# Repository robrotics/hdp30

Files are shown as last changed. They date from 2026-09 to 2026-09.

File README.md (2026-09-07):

# HDP30: a 3D-printable 30:1 pancake harmonic drive actuator

A strain-wave (harmonic) gearbox that bolts onto a standard NEMA 17 stepper,
prints on a bog-standard bed slinger, and costs about **$4 of hardware** per
unit. Half again the reduction of our [HD20](https://github.com/robrotics/hd17)
in a thinner package, using the same screws, the same bearing and the same
motor face.

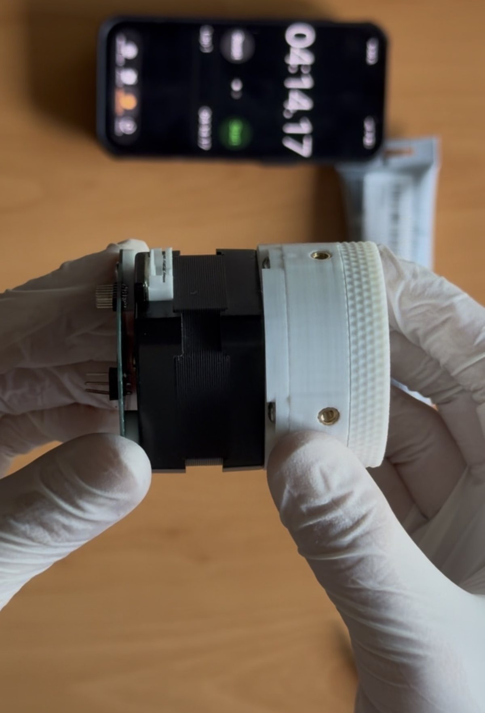
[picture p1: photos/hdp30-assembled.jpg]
The HDP30 assembled on a NEMA 17


| | |
|---|---|
| **Reduction** | 30:1 |
| **Tooth profile** | Cycloidal, module 0.55, 60-tooth flexspline / 62-tooth circular spline |
| **Measured torque** | **not yet measured**, see [Test data](#test-data) |
| **Efficiency** | not yet measured |
| **Backlash** | not yet measured |
| **Motor** | Any NEMA 17 with a 5 mm shaft (same interface plate as the HD20) |
| **Lubrication** | Super Lube synthetic PTFE grease |
| **Printed parts** | 10 pieces across 9 unique parts, including 2 shear pins |
| **Fasteners** | 8 × M3×0.5 × 6 mm button head screws per drive |
| **Hardware cost** | ~$3.96 per actuator |
| **Version** | v1.0 (RevB, 2026-08-30) |
| **License** | [CC BY-SA 4.0](LICENSE) |

> ⚠️ **This revision has not been tested on a load cell yet.** There is no
> torque number, no efficiency number and no backlash number for the HDP30,
> and we would rather ship the files with that gap stated plainly than quote
> you the HD20's figures and let you assume they carry over. They don't: the
> tooth module dropped from 0.8 to 0.55, so the teeth are smaller and the
> engagement is different. Testing is queued; this page gets the numbers when
> the numbers exist.
>
> If you build one and measure it before we do, please
> [open an issue](https://github.com/robrotics/hdp30/issues). We'll credit you.

---

## How it works

Three parts do the work. A **wave generator**, an ellipse riding on 11 loose
5 mm balls in a printed cage, pushes a flexible toothed ring (the
**flexspline**) into an oval, so its teeth engage a rigid ring (the **circular
spline**) at just two points. The circular spline has two more teeth than the
flexspline, so one turn of the motor walks the output around by two teeth.
With a 60-tooth flexspline, that tiny slip per revolution is the 30:1.

New to strain-wave gearing? We wrote a plain-language explainer:
**[robrotics.web.app/learn](https://robrotics.web.app/learn)**.

## What changed from the HD20

The HD20 got 20:1 out of a 40-tooth flexspline at module 0.8. The HDP30 keeps
the same two-tooth difference but packs in **60 teeth at module 0.55**, which
buys half again the reduction at roughly the same pitch diameter, and lets the
whole stack get thinner, hence *pancake*.

Six parts were re-cut for the new profile: the flexspline, both circular
splines, the wave generator, the ball cage and the output preloader. The
**interface plate, the base preloader and the shear pins are unchanged**, and
so is every piece of hardware: same 11 balls, same 30×42×7 bearing, same 8
screws, same 12 inserts. If you have already built an HD20, your leftovers
cover this one.

What you give up is the test data. The HD20 is the measured design; the HDP30
is the newer one.

## What you need

**Not included in the BOM, bring your own:**

- A **NEMA 17 stepper with a 5 mm shaft**. The interface plate is unchanged
  from the HD20, which was validated with an
  [OMC StepperOnline 17HE12-1204S](https://www.omc-stepperonline.com/e-series-nema-17-bipolar-26ncm-36-82oz-in-1-2a-42x42x30mm-4-wires-w-1m-cable-connector-17he12-1204s)
  (42 × 42 × 30 mm, 26 N·cm, 1.2 A, 4-wire) under closed-loop FOC control.
- **4 × M3 screws** to bolt the motor to the interface plate. These are
  separate from the 8 × M3×0.5 × 6 mm screws that hold the drive together,
  which are in the BOM.
- A **soldering iron** for the heat-set inserts, and hex keys.

**Filament:** PLA for everything except the flexspline, which must be **PETG**.

> ⚠️ **Do not print the flexspline in PLA.** It flexes on every single
> revolution. PLA has almost no fatigue life in that duty and will crack.
> This matters more here than on the HD20, not less. Module 0.55 teeth are
> smaller, and the wall they sit on is thin.

## Bill of materials

Machine-readable source: [`bom.json`](bom.json).

| # | Item | Qty | Pack | Pack cost | Per actuator |
|---|---|-----|---|---|---|
| 1 | M3 heat-set inserts | 12 | 100 | $9.99 | $1.20 |
| 2 | M3×0.5 × 6 mm button head, stainless | 8 | 100 | $7.69 | $0.62 |
| 3 | 30 × 42 × 7 mm bearing | 1 | 10 | $16.39 | $1.64 |
| 4 | Set screw | 1 | 50 | $5.69 | $0.11 |
| 5 | 5 mm steel bearing balls | 11 | 200 | $7.20 | $0.40 |
| 6 | Super Lube synthetic grease | 1 | - | - | - |
| | | | | **$46.96 buy-in** | **$3.96 each** |

One tube of grease lasts many builds, so it isn't counted in the per-unit cost.

Parts are sold in packs, so the first actuator costs about $47 in hardware and
every one after that costs about $4, and you'll have enough left over for
eight more.

> **Affiliate disclosure:** the purchase links in `bom.json` and on our website
> are Amazon Associates links. If you buy through one, Robrotics earns a small
> commission at no extra cost to you. Every part listed is what we actually
> used; the links don't change the recommendation.

## Printed parts

| Part | Qty | Material | File |
|---|---|---|---|
| Circular spline (base) | 1 | PLA | `hdp30-circular-spline-base` |
| Circular spline (output) | 1 | PLA | `hdp30-circular-spline-output` |
| Base preloader | 1 | PLA | `hdp30-base-preloader` |
| Output preloader | 1 | PLA | `hdp30-output-preloader` |
| Interface / motor mount | 1 | PLA | `hdp30-interface` |
| Wave generator | 1 | PLA | `hdp30-wave-generator` |
| Ball cage | 1 | PLA | `hdp30-cage` |
| **Flexspline** | 1 | **PETG** | `hdp30-flexspline-petg` |
| Shear pin | **2** | PLA | `hdp30-shear-pin` |

**Both shear pins are required**, and they're the same part printed twice, so
there's only one file. They carry shear load across the output joint directly,
so the connection doesn't have to rely on friction from the preloaded screws to
resist it. The screws clamp; the pins take the sideways load.

### Print settings

The HD20 was printed on a **Bambu Lab P1S** with **Bambu PLA** (and PETG for
the flexspline), and the HDP30 uses the same settings:

- **Arachne** variable-width wall generator
- **One extra wall loop** for strength
- **Seam position: random**, on every part, so a single seam line doesn't stack
  up into a weak spot or a visible ridge on the round surfaces
- **Supports on the output circular spline and the interface.** Everything else
  prints unsupported.

No custom temperatures, no special bed prep.

## Files

```
cad/step/          STEP, for slicing and for CAD work
cad/dxf/           The four tooth profiles, straight out of the harmonic maker
photos/            Build photos
bom.json           Bill of materials (source of truth)
```

Grab the packaged bundles from the
[Releases page](https://github.com/robrotics/hdp30/releases) rather than
cloning, because the STEP files are large.

There are no pre-sliced files in the repo. Import the STEP into your slicer and
use the print settings above, so the geometry you print is always the current
one. A convenience 3MF mesh export is attached to the release for slicers that
won't take STEP. **Note that it doesn't include the two shear pins**, which
are STEP-only.

## Assembly

📹 **Quick assembly run-through:**
**[instagram.com/reel/DclcvVig55a](https://www.instagram.com/reel/DclcvVig55a/)**

That one is fast. A full, properly paced build video is in the works and will
go up on [youtube.com/@robrotics](https://www.youtube.com/@robrotics) and be
linked here. Written step-by-step instructions are being put together
alongside it.

## Make your own version

Two ways in, depending on how deep you want to go.

**Change the tooth profile.** Every profile in this drive came out of our own
free generator, the [harmonic maker](https://robrotics.web.app/gearmaker).
This link opens it with the exact settings used for the HDP30, so you can nudge
one number and export a new DXF:

**[Open the HDP30 profile in the harmonic maker →](https://robrotics.web.app/gearmaker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)**

The four DXFs it produces are checked into [`cad/dxf/`](cad/dxf) if you'd
rather start from ours.

**Change the mechanics.** The full parametric model is public on Onshape:

**[Open the HDP30 in Onshape →](https://cad.onshape.com/documents/319971bd8bd86171560c48e0/w/245bded9ea0f5ce28da60641/e/576f328b49bb8904f021e3ae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)**

Copy it to your own workspace and change what you like: a different motor face,
a different output interface, a different ratio. If you build a variant, we'd
genuinely like to see it: open an issue or tag
[@robrotics](https://www.instagram.com/robrotics).

## Known behaviour

The HDP30 hasn't been characterised yet, so this section is honest about which
column each item comes from. The material-level items carried over from the
[HD20](https://github.com/robrotics/hd17) apply to any printed drive of this
family and are worth reading before you build. The performance items are
**HD20 numbers** and are listed only so you know what kind of behaviour to
expect, not what to expect from this drive.

**Applies to this drive:**

- **PLA creeps under sustained load.** Holding a heavy static load for hours
  will slowly deform the circular splines.
- **Unit-to-unit variation is real.** Two HD20s of the same design differed by
  up to 18% at the same current. Printed gearboxes are not precision parts, and
  smaller teeth won't make that better.
- **Output spline preload is the biggest tuning knob.** On the HD20, tightening
  it further took one unit from 2.37 to 2.55 N·m. Expect it to matter here too.
- **Torque drops after running in.** One HD20 measured 2.32 N·m fresh and
  2.08 N·m after further running. Plan around the run-in figure.

**Not yet known for this drive:** torque, efficiency, backlash, thermal
behaviour, and whether the module 0.55 teeth hold up as well as the 0.8 teeth
under load. That last one is the open question this revision exists to answer.

Found something we haven't listed? Please
[open an issue](https://github.com/robrotics/hdp30/issues) and include your
version, filament, and printer.

## Test data

**None yet.** The load cell rig that produced the
[HD20's torque report](https://robrotics.web.app/archive/hd20-torque-test)
hasn't been run against this revision. When it has, the report will be linked
here and on
[robrotics.web.app/actuators/hdp30](https://robrotics.web.app/actuators/hdp30).

## License

[CC BY-SA 4.0](LICENSE). Use it, change it, sell it. Just credit Robrotics and
share your derivatives under the same license.

**No warranty.** Printed parts fail. Don't put this anywhere a failure could
hurt someone.

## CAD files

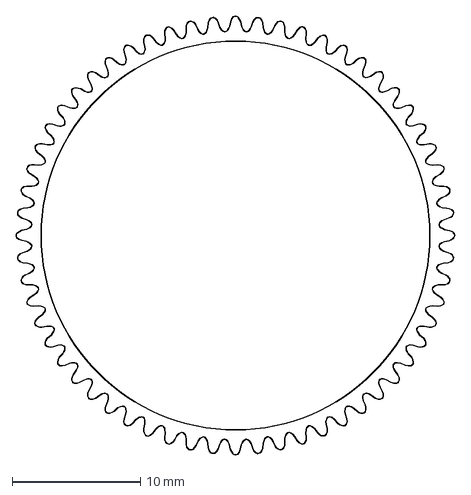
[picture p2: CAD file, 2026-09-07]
cad/dxf/hdp30-flexspline.dxf
34.2 x 34.2 mm

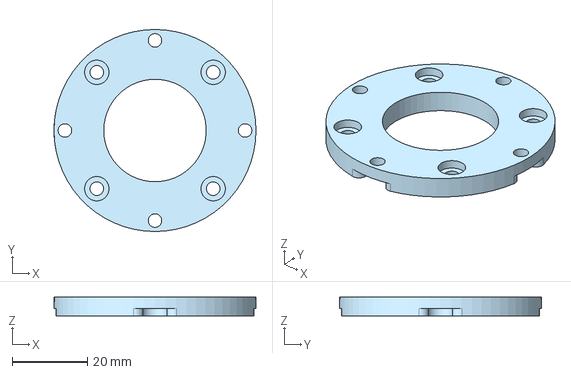
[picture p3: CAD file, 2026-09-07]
cad/step/hdp30-interface.step
53.8 x 53.8 x 5.00 mm

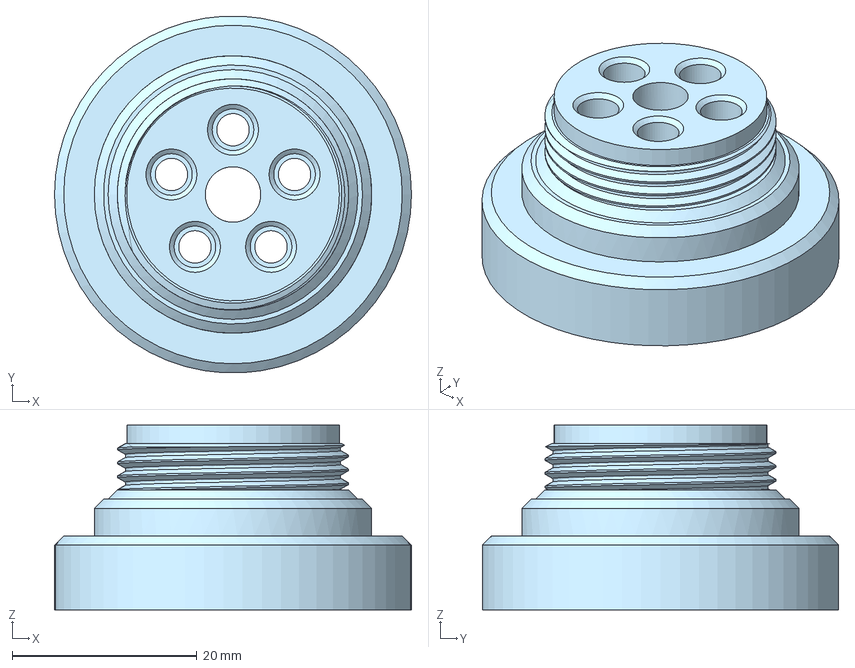
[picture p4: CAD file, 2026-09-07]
cad/step/hdp30-circular-spline-output.step
38.6 x 38.5 x 20.0 mm

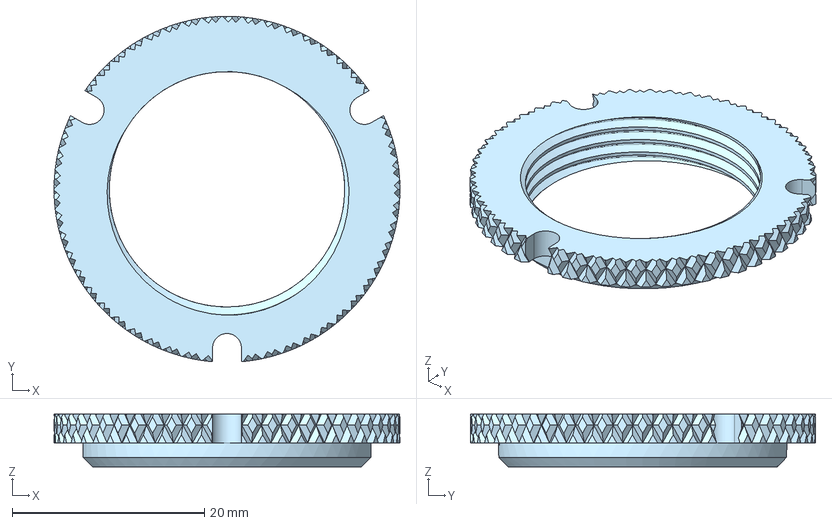
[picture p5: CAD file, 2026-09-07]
cad/step/hdp30-base-preloader.step
36.0 x 35.9 x 5.50 mm

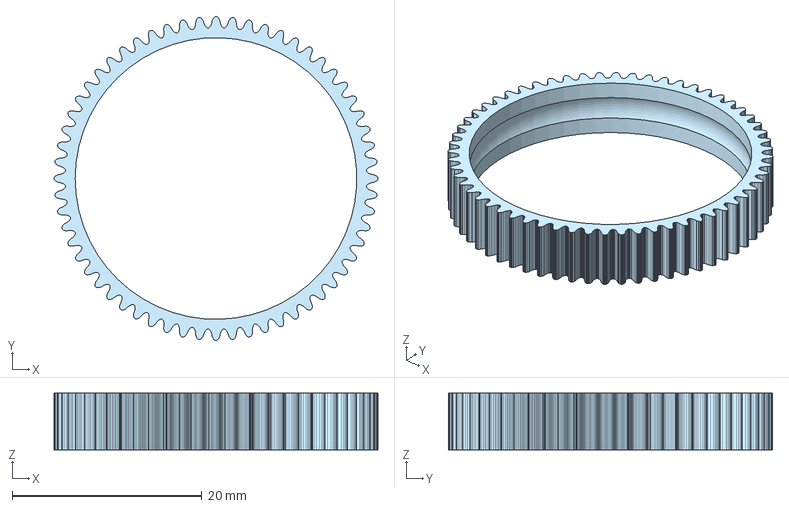
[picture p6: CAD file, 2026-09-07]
cad/step/hdp30-flexspline-petg.step
34.2 x 34.2 x 6.00 mm

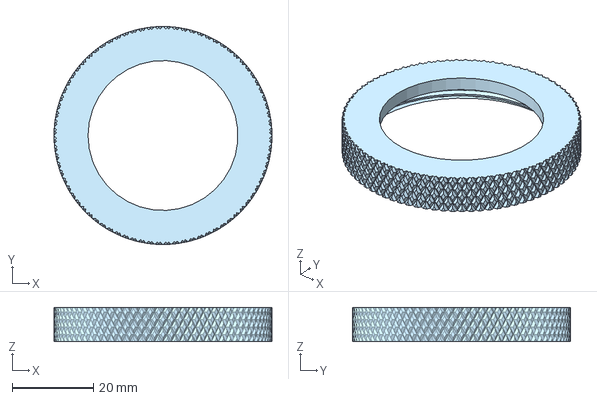
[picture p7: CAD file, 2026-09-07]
cad/step/hdp30-output-preloader.step
53.8 x 53.8 x 8.50 mm

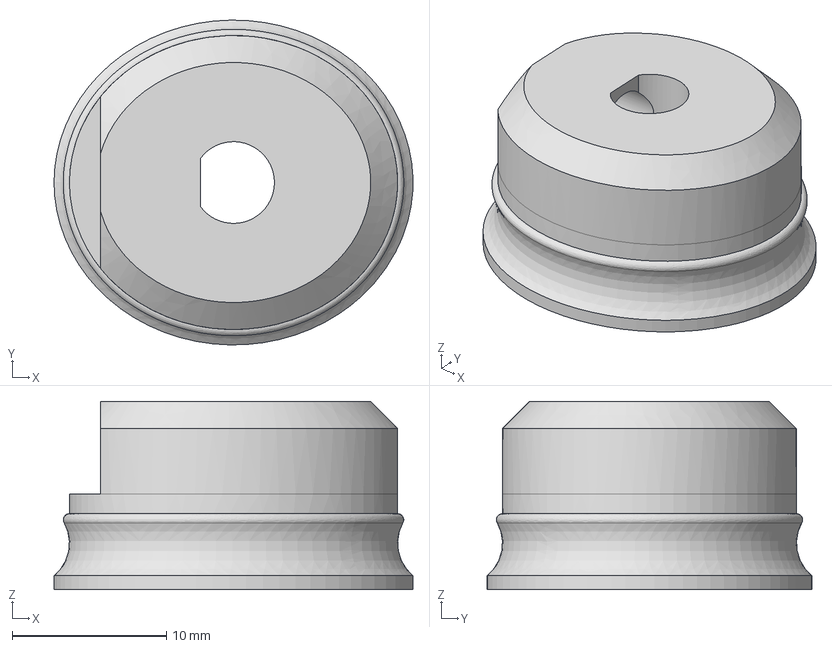
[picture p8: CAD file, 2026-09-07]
cad/step/hdp30-wave-generator.step
23.3 x 21.1 x 12.2 mm

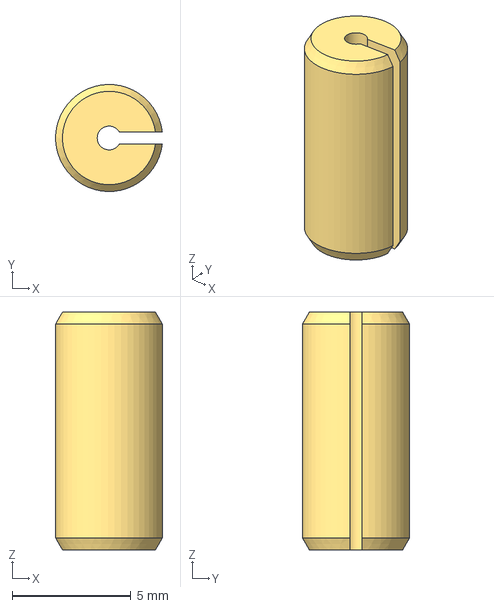
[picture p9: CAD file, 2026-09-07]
cad/step/hdp30-shear-pin.step
4.48 x 4.50 x 10.0 mm

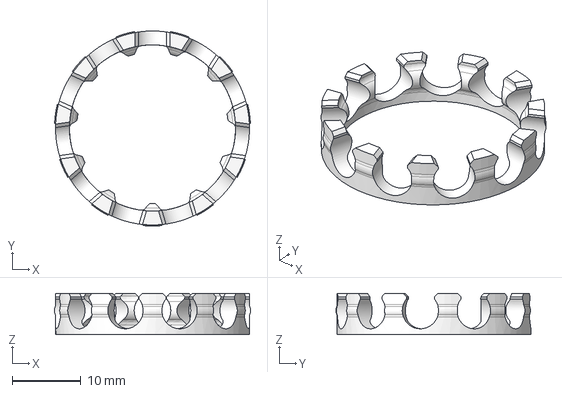
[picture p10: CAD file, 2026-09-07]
cad/step/hdp30-cage.step
28.4 x 28.3 x 6.00 mm

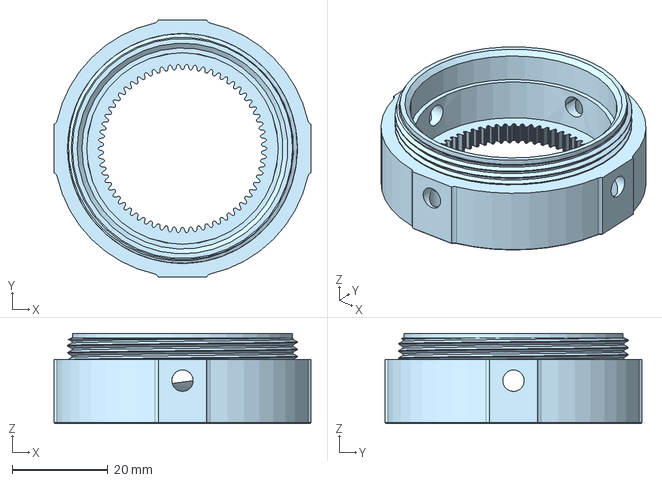
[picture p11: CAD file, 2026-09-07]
cad/step/hdp30-circular-spline-base.step
53.8 x 53.8 x 18.9 mm

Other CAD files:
cad/dxf/hdp30-circular-spline-base.dxf
cad/dxf/hdp30-circular-spline-output.dxf
cad/dxf/hdp30-wave-generator.dxf

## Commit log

2026-09-07 HDP30 v1.0 (RevB) - printable 30:1 pancake harmonic drive
    Module 0.55, 60-tooth flexspline against a 62-tooth circular spline, so
    the reduction goes 20:1 -> 30:1 at roughly the same pitch diameter as the
    HD20 in a thinner stack.
    Six parts were re-cut for the new profile: flexspline, both circular
    splines, wave generator, ball cage and output preloader. The interface
    plate, base preloader and shear pins are unchanged from RevA, and so is
    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
    [hdp30-base-preloader.step, hdp30-cage.step, hdp30-circular-spline-base.dxf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]
2026-09-07 Point the Onshape link at the current view and drop the long dashes
    The Onshape URL now carries the renderMode/uiState params Max supplied,
    so the model opens on the view he set rather than a default camera.
    The em dashes are gone from the prose. Table placeholders that had an
    em dash for "no value" use a plain hyphen instead.
2026-10-18 HDP30 v2.0 (RevC): PLA flexspline, alignment tool, third shear pin
    RevC moves the flexspline from PETG to PLA (same geometry) and adds a
    printed alignment tool that sets the wave generator height on the motor
    shaft. Both circular splines are re-cut for a third shear pin. The tooth
    profile, cage, interface, preloaders, wave generator and hardware are
    unchanged from v1.0.
    Load-cell tested on 2026-10-18: held 1.49 N·m with no tooth skips,
    cracking starts at about 1.5 N·m and the flexspline wall broke at about
    2.0 N·m. Fatigue life of the PLA flexspline is not tested yet, and the
    README says so.
2026-10-19 Rinnegan drive name, endurance results and RevC photos
    Calls HDP30 the Rinnegan drive in the README, adds the 2026-10-18
    endurance results (5,744 flex cycles at 1.0-1.2 N·m with no damage,
    cracking from 1.5-1.67 N·m) and changes the guidance to peaks under
    about 1.3 N·m and about 0.6 A of motor current. Adds two RevC photos.
2026-10-24 Add the slow-speed backlash result: about 0.03° (2 arcmin)
    Twelve 5 RPM runs on a third RevC unit put the backlash at about 0.03°
    at the output, with no run above about 0.1°. Replaces "under 0.25°,
    too small to measure".
2026-10-24 Lead the README with the 2 arcmin backlash
